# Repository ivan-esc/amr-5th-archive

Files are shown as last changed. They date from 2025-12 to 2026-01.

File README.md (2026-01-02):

AMR + AGV DIFFERENTIAL ROBOT - OMRON PROJECT (Mechatronics Eng. 5th semester AD25)
===================================
The objective of this project was to design a differential-wheeled robot capable of:
- Being operated manually with a mobile app joystick.
- Operating under a configurable AGV mode with station color detection.
- AMR mode with complete custom route configuration.
Following safety protocols regarding velocity and acceleration curves, energy consumption, emergency stops and awareness of nearby objects.
-----------------------------------
The repository includes the following:
- STM32f0Discovery project files (C)
- ESP32 project files (C++)
- Webpage history logs and final used file. (Javascript, HTML, CSS)
- MIT App Inventor project file for mobile app. (Block-based)
-----------------------------------
Main aspects of the project include:
- Direct register-level configuration of GPIOs using STM32 clock trees and peripheral memory maps.
- Timer prescaling and compare/capture configuration for PWM generation, ultrasonic time-of-flight measurement, and interrupt-driven non-blocking task scheduling.
- Implementation of UART communication with custom frame synchronization and desynchronization recovery between a Bluetooth client, STM32, and ESP32.
- Integration of multiple peripheral sensors using the I²C communication protocol on an STM32F0-based platform.
- Implementation of encoder-based odometry with inertial correction using first-order digital low-pass filtering.
- Closed-loop PID motor control using PWM, with acceleration-limited velocity references to mitigate current spikes and mechanical stress.
- AGV operation mode featuring robust line-following algorithms and floor-based station identification logic.
- Autonomous mobile robot (AMR) control supporting dynamically uploaded navigation routes.
- Implementation of visual feedback cues using addressable LED control libraries on the ESP32.
- ADC acquisition and conversion for temperature monitoring and battery-level measurement using voltage dividers.
- Additional audio and visual feedback features using buzzer-driven melodies and programmable LED patterns.
- Real-time WebSocket communication between the ESP32 and a web-based AMR control interface.
- Custom parametric trajectory generation using sinusoidal functions for x–y coordinate computation.
- Route smoothing for user-drawn paths using combined Chaikin subdivision and Gaussian filtering techniques.
- CSS-based layout and styling for an intuitive and user-friendly web interface.

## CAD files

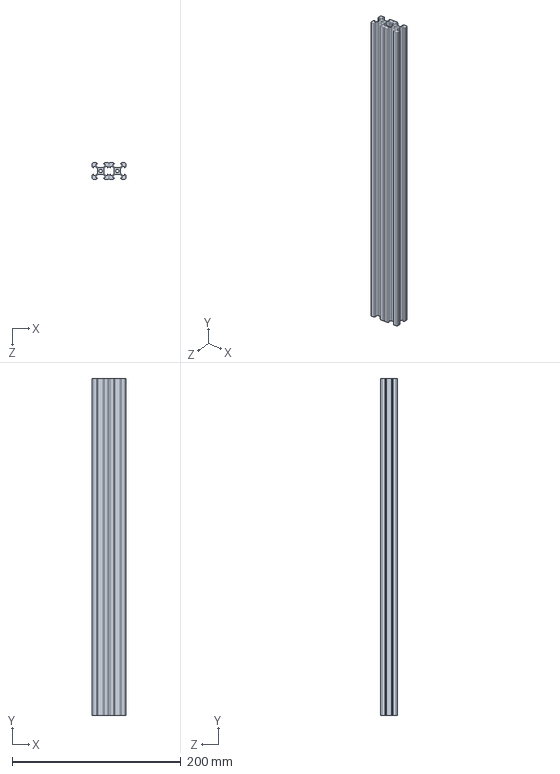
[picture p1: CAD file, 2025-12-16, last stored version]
Solidworksassembly/perfil_2040.SLDASM
40.0 x 400.0 x 20.0 mm
perfil_2020_lateral x 2

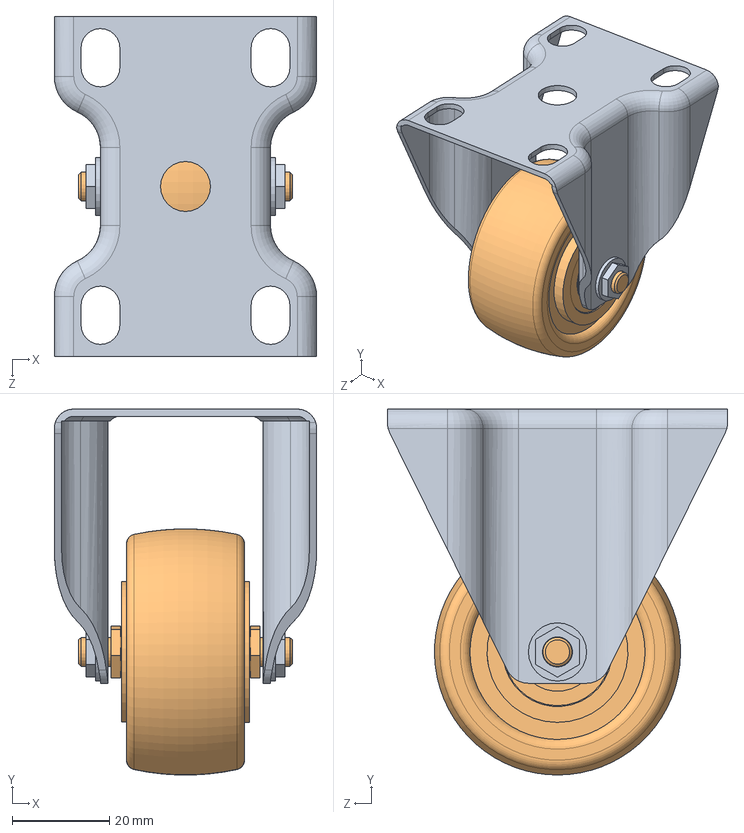
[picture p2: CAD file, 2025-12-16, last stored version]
Solidworksassembly/Standart_parts/2-inch-wheel-swivel-1.snapshot.1/CASTER WHEEL (2 inch) ASSY/2 inch WHEEL (FIXED) ASSY.SLDASM
54.0 x 75.3 x 70.0 mm
2 inch WHEEL BASE (FIXED)
2 inch WHEEL

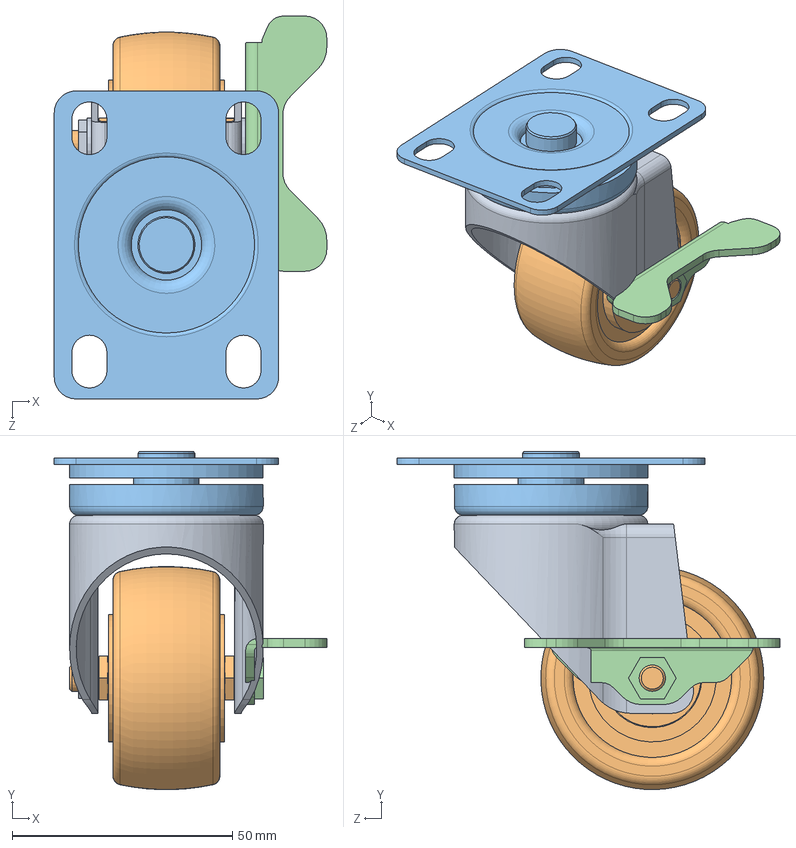
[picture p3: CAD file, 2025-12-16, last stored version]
Solidworksassembly/Standart_parts/2-inch-wheel-swivel-1.snapshot.1/CASTER WHEEL (2 inch) ASSY/2 inch WHEEL (SWIVEL) with BRAKES ASSY 2.SLDASM
61.9 x 76.8 x 87.0 mm
2 inch WHEEL BASE 2 (SWIVEL) with BRAKES
2 inch WHEEL
2 inch WHEEL UPPER BASE (SWIVEL) with BRAKES
CASTER WHEEL BASE LOCK (2IN)

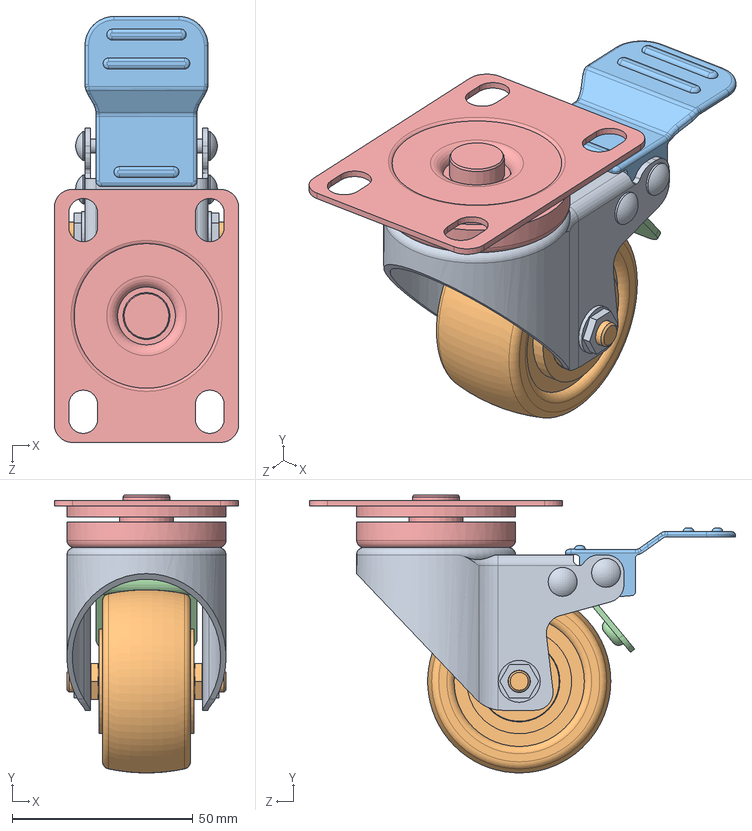
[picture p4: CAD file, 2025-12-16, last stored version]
Solidworksassembly/Standart_parts/2-inch-wheel-swivel-1.snapshot.1/CASTER WHEEL (2 inch) ASSY/2 inch WHEEL (SWIVEL) with BRAKES ASSY.SLDASM
51.0 x 76.8 x 117.8 mm
2 inch WHEEL BASE (SWIVEL) with BRAKES
2 inch WHEEL
2 inch WHEEL UPPER BASE - STOPPER 1 (SWIVEL) with BRAKES
2 inch WHEEL UPPER BASE - STOPPER 2 (SWIVEL) with BRAKES
2 inch WHEEL UPPER BASE (SWIVEL) with BRAKES

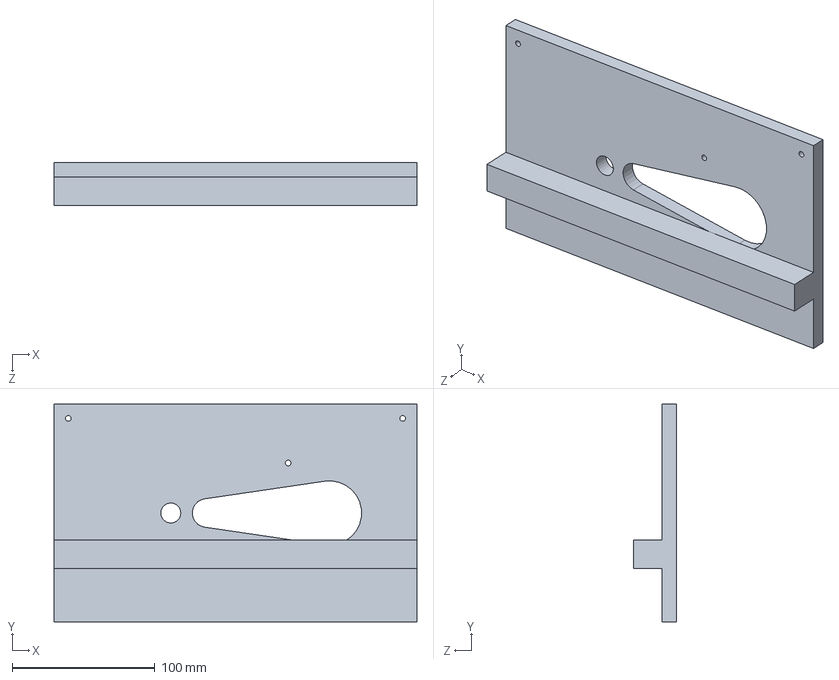
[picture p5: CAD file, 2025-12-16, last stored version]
Solidworksassembly/Actuadores/Motor_WSJ/base_dummy.SLDPRT
254.0 x 152.4 x 30.0 mm

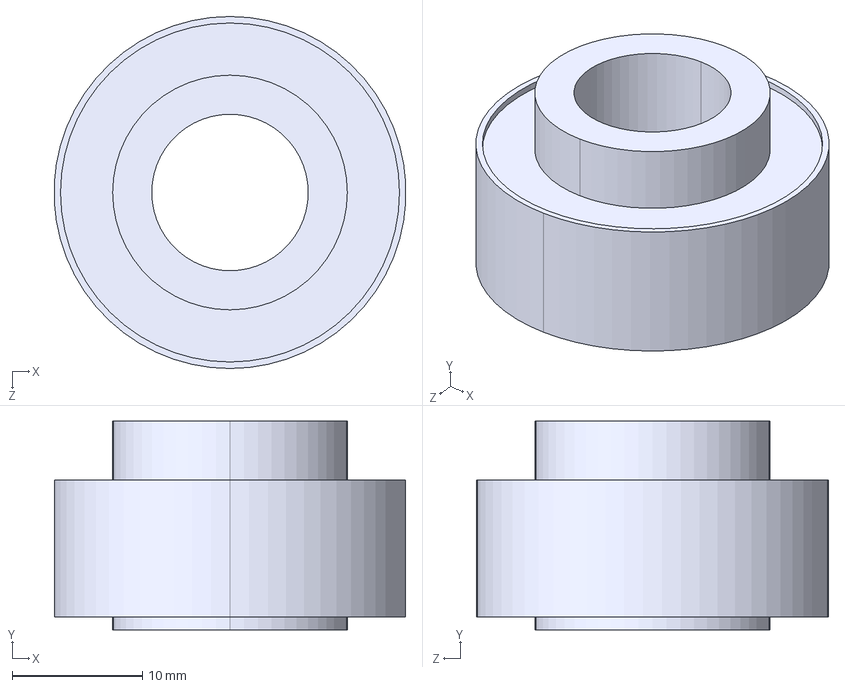
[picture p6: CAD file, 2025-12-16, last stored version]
Solidworksassembly/Actuadores/Motor_WSJ/flanged-support-bearing-kfl001-1.snapshot.2/подшипник KFL001.STEP
27.0 x 16.0 x 27.0 mm

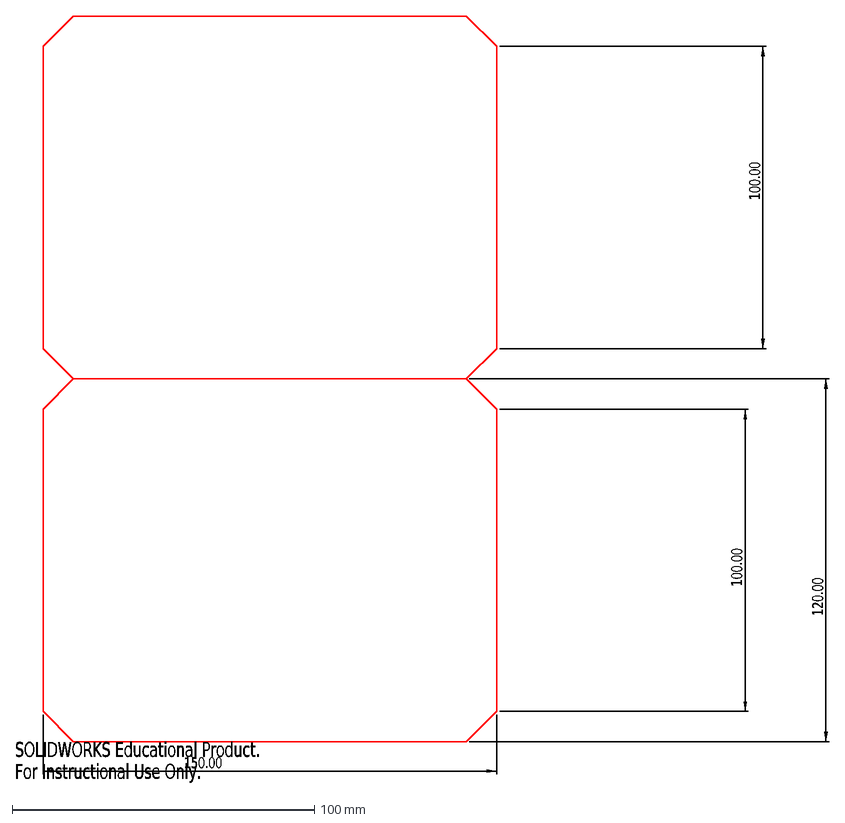
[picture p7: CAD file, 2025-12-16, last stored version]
Solidworksassembly/Addons/rectrojos.DXF
150.00
120.00
100.00
SOLIDWORKS Educational Product.
For Instructional Use Only.

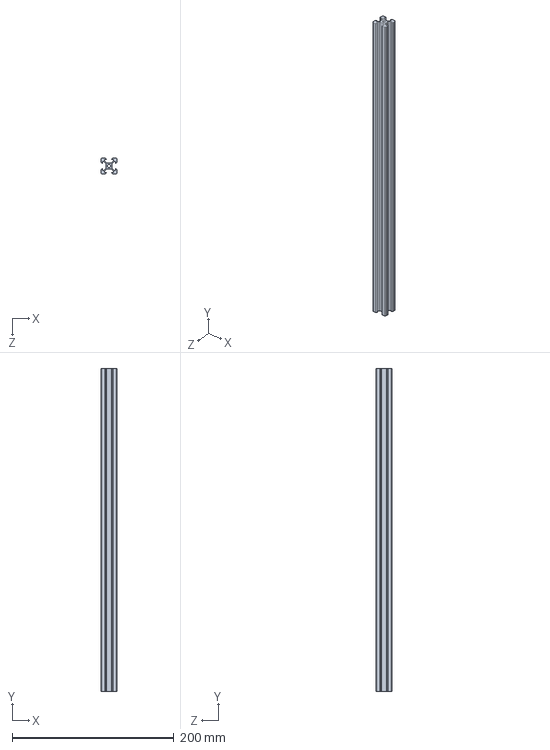
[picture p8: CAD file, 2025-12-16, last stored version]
Solidworksassembly/Diseño/perfil_2020_lateral.SLDPRT
20.0 x 400.0 x 20.0 mm

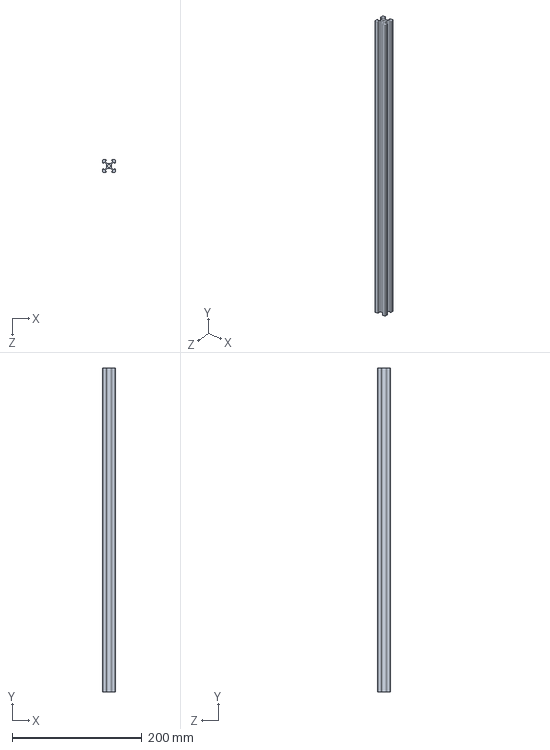
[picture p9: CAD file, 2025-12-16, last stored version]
Solidworksassembly/perfil_2020.SLDPRT
20.0 x 500.0 x 20.0 mm

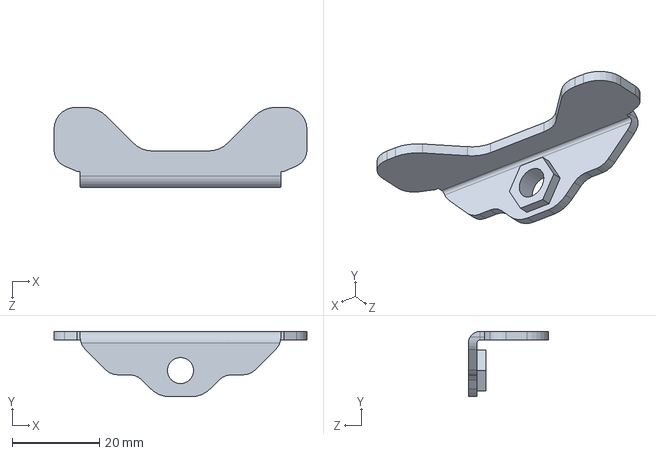
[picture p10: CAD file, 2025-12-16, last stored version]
Solidworksassembly/Standart_parts/2-inch-wheel-swivel-1.snapshot.1/CASTER WHEEL (2 inch) ASSY/CASTER WHEEL BASE LOCK (2IN).SLDPRT
58.0 x 15.0 x 18.4 mm

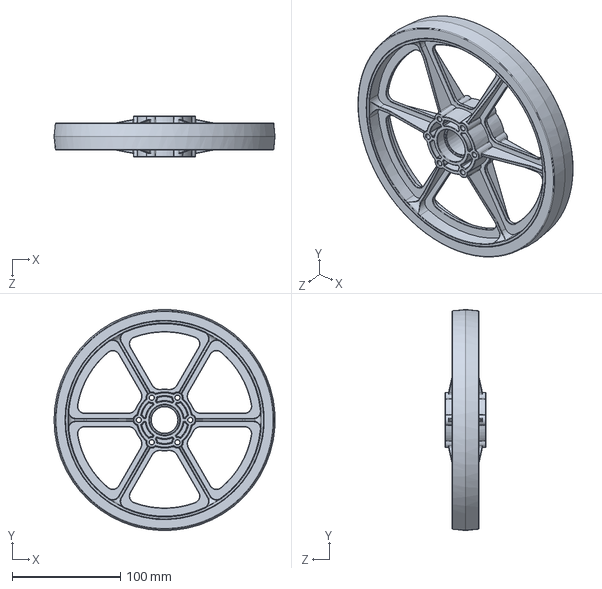
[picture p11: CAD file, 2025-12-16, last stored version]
Solidworksassembly/Standart_parts/am-0420 8in Wheel.SLDPRT
204.2 x 204.3 x 38.1 mm

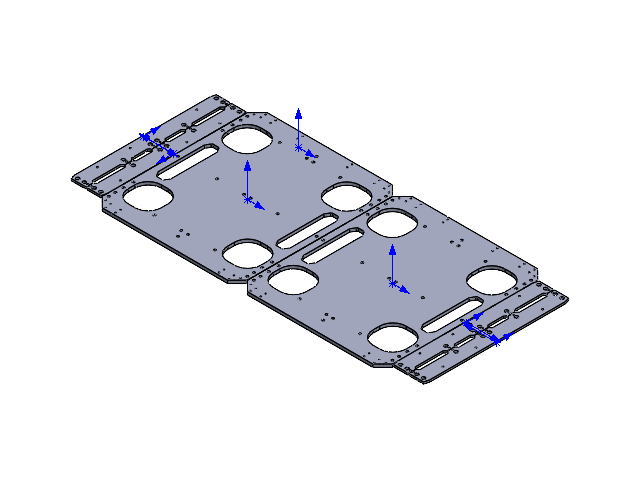
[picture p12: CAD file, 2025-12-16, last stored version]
Solidworksassembly/Manufactura/corte_laser_bases_x7.SLDASM
base_robot x 2
union_top x 4

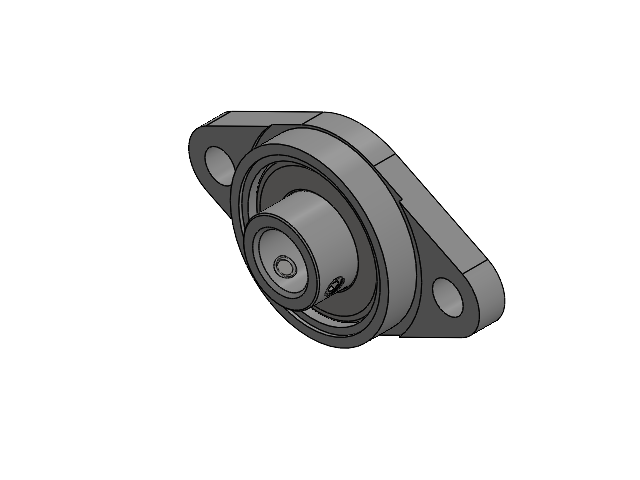
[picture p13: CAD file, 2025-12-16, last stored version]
Solidworksassembly/Standart_parts/KFL08/Zinc Alloy Pillow Block Flange Bearing KFL08 ID-8mm.SLDASM
Flange
Bearing 61801-2Z GB_T 276-94
DIN 988 - 13 x 19 x 1 x 2
Collar 8x12.35x11.35
IS_ 6094 - M3 x 2(1) x 3

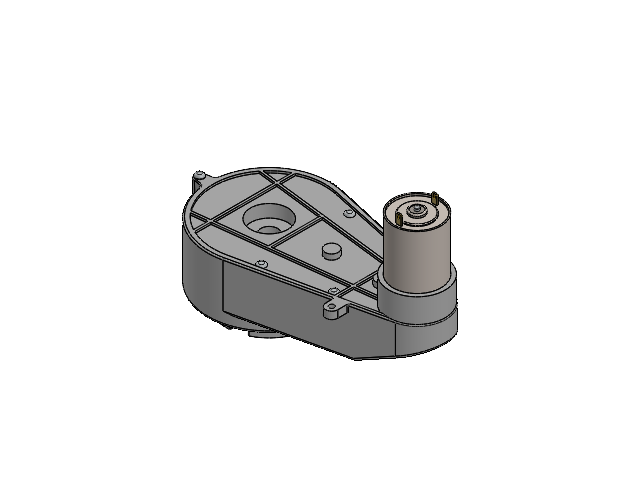
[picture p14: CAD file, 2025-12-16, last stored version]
Solidworksassembly/Actuadores/Motor_WSJ/motor_hub_WJS.SLDASM
motor_WJS
hub_motor_WJS

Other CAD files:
Solidworksassembly/Standart_parts/2-inch-wheel-swivel-1.snapshot.1/CASTER WHEEL (2 inch) ASSY/2 inch WHEEL (FIXED) ASSY 2.SLDASM
Solidworksassembly/Diseño/corte_laser_bases.SLDASM
Solidworksassembly/Standart_parts/2-inch-wheel-swivel-1.snapshot.1/CASTER WHEEL (2 inch) ASSY/2 inch WHEEL (SWIVEL) without BRAKES ASSY.SLDASM
Solidworksassembly/Standart_parts/KFL08/Collar 8x12.35x11.35.SLDPRT
Solidworksassembly/Actuadores/Motor_WSJ/base_motor.SLDPRT
Solidworksassembly/Actuadores/Motor_WSJ/base_wjs.DXF
Solidworksassembly/Actuadores/Motor_WSJ/base_wjs.SLDPRT
Solidworksassembly/Actuadores/Motor_WSJ/flanged-support-bearing-kfl001-1.snapshot.2/основние подшипника KFL001.SLDPRT
Solidworksassembly/Actuadores/Motor_WSJ/flanged-support-bearing-kfl001-1.snapshot.2/основние подшипника KFL001.STEP
Solidworksassembly/Actuadores/Motor_WSJ/flanged-support-bearing-kfl001-1.snapshot.2/подшипник KFL001.SLDPRT
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

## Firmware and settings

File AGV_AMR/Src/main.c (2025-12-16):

/*CODIGO EQUIPO NEGRO */

#include <stdint.h>
#include "stm32f051x8.h"
#include <stdlib.h>
#include <math.h>
#include <stdbool.h>

// Headers
#include "motor_pwm.h"
#include "encoders.h"
#include "ultrasonic.h"
#include "bluetooth.h"
#include "esp32_com.h"
#include "pid_diff_drive.h"
#include "i2c_color_imu.h"
#include "line_follow.h"
#include "odometry.h"
#include "amr_mode.h"

volatile uint32_t t = 0; //tiempo base
volatile uint8_t emergency_on = 0; //toggle emergencia


float w_ll = 0.0f;
float w_rr = 0.0f;
float VV = 0.0f;
float WW = 0.0f;

volatile int16_t x = 0; // Reworked mapped coordinate
volatile int16_t y = 0; // Reworked mapped coordinate


/////////////////////////////////////////////////////////////////////////////////////////////
///////////////////////////////    DECLARACION DE FUNCIONES    //////////////////////////////
/////////////////////////////////////////////////////////////////////////////////////////////

void BT_process_data(void);

void TIM14_Init(void); 			//10ms clock init
void ManualDrive(void);	//Manual mode (1) desired RPMs

static uint8_t amr_initialized = 0;   // 0 = not initialized, 1 = init done
void reset_references(void);

void emergency_stop(void);				//Actions when stopped
void check_emergency_buttons(void);		//EXTI for Emergency Pins (pending assignment)
void init_emergency_buttons(void);		//EXTI channel init for emergency
void PC7_Button_Check(void);
void PC7_Button_Init(void);

void SelectManualLEDCommand(void);		//Manual mode joystick LED aplication


int main(void)
{

	RCC->AHBENR |= RCC_AHBENR_GPIOBEN;
	RCC->APB2ENR |= RCC_APB2ENR_SYSCFGCOMPEN;
	RCC->APB1ENR |= RCC_APB1ENR_TIM3EN;
	NVIC->ISER[0] |= (1 << EXTI4_15_IRQn);

	i2c1_init(); //COLOR AND IMU

	USART2_Init(); //BLUETOOTH INIT CHECK
	USART1_Init(); //ESP32 COM INIT CHECK

	TIM14_Init(); //ROUTINE TIMER
	pwm_init(); //MOTOR CHANNELS CHECK
	IR_Sensors_Init(); //LINE FOLLOWER
	init_GPIO_EXTI_encoders(); //ENCODERS CHECK

	TIM3_init(); //ULTRASONIC TIMING CHECK
	init_GPIO_EXTI_ultrasonic(); //ULTRASONIC INIT CHECK

	__enable_irq(); //ENABLE INTERRUPTIONS CHECK
	mpu6050_init();
	//TCS34725_Init();

	Odometry_Init();
	init_emergency_buttons();
	PC7_Button_Init();

	AMR_Init();          // reset odometry, set internals, etc.

    /* Loop forever */

  	while (1){
        check_emergency_buttons();
  		if (imu_read_flag) {
			imu_read_flag = 0;
			imu_routine();
  		}
		if (color_read_flag) {
			color_read_flag = 0;
			color_detect_routine();
		}
	}
}




void TIM14_Init(void) { //10ms Timer Setup
	RCC->APB1ENR |= RCC_APB1ENR_TIM14EN;
    TIM14->PSC = 8 - 1;      // 8MHz/8 = 1MHz
    TIM14->ARR = 10000 - 1;  // 10ms period
    TIM14->DIER |= TIM_DIER_UIE;
    TIM14->CR1 |= TIM_CR1_CEN;
	NVIC_SetPriority(TIM14_IRQn, 1);  // Lower value = higher priority
    NVIC_EnableIRQ(TIM14_IRQn);
}
void TIM14_IRQHandler(void) { //10 ms timer
    if(TIM14->SR & TIM_SR_UIF) {
        TIM14->SR &= ~TIM_SR_UIF;  // Clear interrupt flag
        t += 10;

        //CONTINUOS SENSOR READS
        imu_read_flag = 1;
        check_emergency_buttons();
        velocidad_encoder();
		hcsr04_read();
		Odometry_Update();

        if (rx_buffer[0]!=255){PC7_Button_Check();}

        switch(menu_button){
        case 0: // OFF - Just Connected
        	reset_references();
        	break;
        case 1: //MANUAL MODE: idle
        	reset_references();
        	LED_action = 14;
        	break;
        case 2: //MANUAL MODE: running
        	ManualDrive();
        	break;
        case 3: //LINE FOLLOW: idle configuration
        	reset_references();
        	LED_action = 7;
        	break;
        case 4: // LINE FOLLOW MODE
        {
            if((distance_cm[2]>30.0f) && (distance_cm[0]>15.0f) && (distance_cm[3]>15.0f)){
				if(linea){
					seguir();}
            break;
            }
            else{
                VW_DifferentialDrive(0.0f,0.0f);
            	near_obj=1 ;
				V_current = 0;
				LED_action = 11;
				W_current = 0;
			break;
            }
        }
		case 5: //AMR: idle configuration
			reset_references();
			if(valid_indexes > 0){
				LED_action = 21;
			}
			else{
				LED_action = 19;
			}
			break;
        case 6: //AMR: RUNNING
            if((distance_cm[2]>30.0f) && (distance_cm[0]>15.0f) && (distance_cm[3]>15.0f)){
				LED_action = 0;
				if (!amr_initialized) {
					AMR_Start();
					amr_initialized = 1;
				}
				AMR_Update();

			break;
			}
			else{
				VW_DifferentialDrive(0.0f,0.0f);
				near_obj=1 ;
				V_current = 0;
				LED_action = 11;
				W_current = 0;
			break;
			}
        case 7: //SETTINGS
        	LED_action = 12;
        	reset_references();
        	break;
        case 8: // ESTOP?
        	reset_references();
        	LED_action = 13;
        	break;

        case 20: /// RGB TEST
			reset_references();
        	LED_action = 15;
			break;

		case 21: /// song1
			reset_references();
			LED_action = 31;
			break;

		case 22: /// song1
			reset_references();
			LED_action = 30;
			break;
		}


		static uint8_t last_led_action = 0xFF;
		uint8_t cur = LED_action; // Mandar comand a ESP32 solo cuando cambia
		if (cur != last_led_action) {
			USART1_send(cur);
			last_led_action = cur;
		}

		if (t >= 70) { //MANDAR DATOS DE BLUETOOTH CADA 200ms
			BT_process_data();
			BT_SendTelemetry();
			t = 0;
		}
    }
}



void ManualDrive(void){
	//Logic calculation based on 250x250 map, where 125x125 is defined as center
	//Assume a +-30 deadzone for generous inputs

	 x = raw_x - 125; //Set initial coords to (0,0)
     y = 125- raw_y;
     if (abs(x) < 30){ x = 0;}
     if (abs(y) < 30){ y = 0;}
     //Normalize
     V_req = y*0.8f/125.0f; //Max speed will be set to 0.8m/s for plot convenience
     W_req = x*0.8f*2.5f/125.0f; // Angular speed

     VW_DifferentialDrive(V_req,W_req);
     SelectManualLEDCommand();
}


void BT_process_data(void) {
    // Convert from RPM to rad/s
    w_ll = rpm_1_filtered * 2.0f * 3.14159265359f / 60.0f;
    w_rr = rpm_2_filtered * 2.0f * 3.14159265359f / 60.0f;

    // Compute linear and angular velocity
    VV = (WHEEL_RADIUS * (w_rr + w_ll)) / 2.0f;
    WW = (WHEEL_RADIUS * (w_rr - w_ll)) / WHEEL_DISTANCE;

    linear_velocity = (uint8_t)((fabsf(VV)*10) + 0.5f);
    angular_velocity = (uint8_t)((fabsf(WW)*10) + 0.5f);

    tmp_data = temperature10;
    //voltage_sent = voltage10;
    voltage_sent = 118;

    posx_small = (uint8_t)(pos_x_mm & 0xFF);        // byte bajo  (LSB)
    posx_big   = (uint8_t)((pos_x_mm >> 8) & 0xFF); // byte alto  (MSB)

    posy_small = (uint8_t)(pos_y_mm & 0xFF);
    posy_big   = (uint8_t)((pos_y_mm >> 8) & 0xFF);

}

void init_emergency_buttons(void) {
    // Enable GPIOC clock
    RCC->AHBENR |= RCC_AHBENR_GPIOCEN;

    // Set PC6 as inputs (MODER = 00)
    GPIOC->MODER &= ~(3 << (6 * 2));

    // Optional: enable pull-downs if buttons are active-high
    GPIOC->PUPDR &= ~(3 << (6 * 2)); // Clear
}
void check_emergency_buttons(void) {
    // If PC6 is HIGH
    if ((GPIOC->IDR & (1 << 6))) {
        emergency_stop();
    }
    else{
    	emergency_on = 0;
    }
}
void emergency_stop(void) {
    menu_button = 0;
    emergency_on = 1;
    reset_references();
	LED_action = 13;
}

// ----- Initialize PC7 as input -----
void PC7_Button_Init(void) {
    // Enable GPIOC clock
    RCC->AHBENR |= RCC_AHBENR_GPIOCEN;

    // Set PC7 as input (MODER = 00)
    GPIOC->MODER &= ~(3 << (7*2));

    // Optional: enable pull-down or pull-up if needed
    GPIOC->PUPDR &= ~(3 << (7*2));   // clear
    GPIOC->PUPDR |=  (1 << (7*2));   // pull-up
}
// ----- Check PC7 periodically -----
void PC7_Button_Check(void) {
    if (GPIOC->IDR & (1 << 7)) {  // if PC7 is HIGH
        menu_button = 6;
    }
    else {
        menu_button = 0;          // optional: reset if low
    }
}

void SelectManualLEDCommand(void) {
    // Default = idle
    int cmd = 0;
    if (y > 30 && abs(x) < 40) {
        // Forward
        cmd = 3;
    }
    else if (y < -30 && abs(x) < 40) {
        // Backward
        cmd = 4;
    }
    else if (x < -30 /*&& abs(y) < 40*/) {
        // Left
        cmd = 5;
    }
    else if (x > 30 /*&& abs(y) < 40*/) {
        // Right
        cmd = 6;
    }
    else if (abs(x) < 30 && abs(y) < 30) {
        // Deadzone → Idle
        cmd = 0;
    }
    LED_action = cmd;
}
void reset_references(void){
	PID_PWM(0,0);
	left_RPWM(0);
	left_LPWM(0);
	right_RPWM(0);
	right_LPWM(0);
	rpm_ref_left=0;
	rpm_ref_right=0;
	V_current = 0.0f;
	W_current = 0.0f;
	last_position_error = 0.0f;
	exit_timer = 0;
	station_done = true;     // back to normal mode
	leaving_station = false;  // fully reset
	counter_stations = 1;
	AMR_Stop();             // <- resets AMR state machine, indices, odometry via Reset_x_y()
	amr_initialized = 0;    // allow re-init next time AMR is selected


}

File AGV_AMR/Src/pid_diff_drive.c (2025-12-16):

///////////////////////////////////////////////
////// PID AND DIFFERENTIAL DRIVE SOURCE //////
///////////////////////////////////////////////
/*
 INPUT: V_req and W_req rpm_ref_l_r
 OUTPUT: PID FOR PWM
 */

#include "pid_diff_drive.h"

// Left wheel PID
float error_l     = 0.0f;
float error_l_dt   = 0.0f;
float int_error_l = 0.0f;
float der_error_l = 0.0f;

// Right wheel PID
float error_r     = 0.0f;
float error_r_dt   = 0.0f;
float int_error_r = 0.0f;
float der_error_r = 0.0f;

float kp_l = 10.0f;
float ki_l = 3.0f;
float kd_l = 0.0f;

float kp_r = 10.0f;
float ki_r = 3.0f;
float kd_r = 0.0f;

int16_t pwm_left_cmd = 0,pwm_right_cmd = 0;
float pwm_l = 0,pwm_r = 0;

//avoids killing the hbridge
float last_pwm_l = 0.0f, last_pwm_r = 0.0f;
uint8_t changed_direction_l = 0, changed_direction_r = 0;

float V_req = 0; //Linear speed MAX: 2m/s
float W_req = 0; //Angular speed MAX: 2rad/s i think
float w_l = 0, w_r = 0; // En rad/s
float rpm_ref_left = 0, rpm_ref_right = 0; //convert w_l and w_r to rpms

void PID_PWM(float ref_l,float ref_r){ //1 = left, 2 = right
    // ----- LEFT MOTOR PID -----
	error_l = ref_l - rpm_1_filtered;
	if (fabsf(pwm_l) < 650.0f && fabsf(ref_l) > 1.0f) {
		int_error_l += 0.01f * error_l;
	}
	else if (fabsf(ref_l) <= 1.0f) {
		int_error_l = 0.0f;
	}
	der_error_l = (error_l - error_l_dt) / 0.01f;
	error_l_dt = error_l;

	// ----- RIGHT MOTOR PID -----
	error_r = ref_r - rpm_2_filtered;

	if (fabsf(pwm_r) < 650.0f && fabsf(ref_r) > 1.0f) {
	    int_error_r += 0.01f * error_r;
	}
	else if (fabsf(ref_r) <= 1.0f) {
	    int_error_r = 0.0f;
	}

	der_error_r = (error_r - error_r_dt) / 0.01f;
	error_r_dt = error_r;


	pwm_l = kp_l * error_l + ki_l * int_error_l + kd_l * der_error_l;
	pwm_r = kp_r * error_r + ki_r * int_error_r + kd_r * der_error_r;

	// ----- ANTI WIND UP (MAX PWM EXPERIMENTAL AROUND 2M/S = 77% DUTY -----
	if (pwm_l > 650.0f) {
		pwm_l = 650.0f;
	} else if (pwm_l < -650.0f) {
		pwm_l = -650.0f;
	}
	if (pwm_r > 650.0f) {
		pwm_r = 650.0f;
	} else if (pwm_r < -650.0f) {
		pwm_r = -650.0f;
	}

	// Map to actual macros (BTS driver expects positive duty and direction pins)
	// ====================================================
	// SAFETY LOGIC — DIRECTION CHANGE DETECTION
	// ====================================================
	// Detect sign change (zero crossing)
	if ((last_pwm_l * pwm_l < 0.0f) || (fabsf(pwm_l) < 5.0f)) {
		left_LPWM(0);
		left_RPWM(0);
		changed_direction_l = 1;
	} else {
		changed_direction_l = 0;
	}

	if ((last_pwm_r * pwm_r < 0.0f) || (fabsf(pwm_r) < 5.0f)) {
		right_LPWM(0);
		right_RPWM(0);
		changed_direction_r = 1;
	} else {
		changed_direction_r = 0;
	}

	// ====================================================
	// APPLY PWM ONLY IF NO CHANGE
	// ====================================================
	if (!changed_direction_l) {
		if (pwm_l >= 0.0f) {
			left_RPWM((uint16_t)pwm_l);
			left_LPWM(0);
		} else {
			left_LPWM((uint16_t)(-pwm_l));
			left_RPWM(0);
		}
	}

	if (!changed_direction_r) {
		if (pwm_r >= 0.0f) {
			right_RPWM((uint16_t)pwm_r);
			right_LPWM(0);
		} else {
			right_LPWM((uint16_t)(-pwm_r));
			right_RPWM(0);
		}
	}
	//Safety delta
	last_pwm_l = pwm_l;
	last_pwm_r = pwm_r;
	 // Debug save
	pwm_left_cmd = (int)pwm_l;
	pwm_right_cmd = (int)pwm_r;
}

void VW_DifferentialDrive(float V_req,float W_req){
    w_l = (V_req / WHEEL_RADIUS) + (WHEEL_DISTANCE * W_req / (2.0f * WHEEL_RADIUS));
    w_r = (V_req / WHEEL_RADIUS) - (WHEEL_DISTANCE * W_req / (2.0f * WHEEL_RADIUS));

    rpm_ref_left  = w_l * 60.0f / (2.0f * 3.14159265358979323846f);
    rpm_ref_right = w_r * 60.0f / (2.0f * 3.14159265358979323846f);

    PID_PWM(rpm_ref_left,rpm_ref_right);

}

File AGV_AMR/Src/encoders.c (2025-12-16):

//////////////////////////////
////// ENCODERS  SOURCE //////
//////////////////////////////
/*
 INPUT: EXTI-PULSES AND INIT
 OUTPUT: RPM-FILTERED
 */

#include "encoders.h"

/////////////////////////////////////////////////////////////////////////////////////////////
///////////////////////////////      ENCODERS            ////////////////////////////////////
/////////////////////////////////////////////////////////////////////////////////////////////

volatile int32_t encoderPos1 = 0, encoderPos2 = 0; //Absolute Position based on start up
volatile uint8_t direction1 = 0, direction2 = 0; // 1 cockwise, 2 counter cockwise
volatile float delta_Pos1 = 0.0f, delta_Pos2 = 0.0f; //Diferencial cada 10ms
volatile float lastPos1 = 0.0f, lastPos2 = 0.0f; //Referencia encoder pos para delta

#define Aa 0.0951625819640404f   // coefficient for input (transfer funct)
#define Bb -0.904837418035960f   // coefficient for previous output (transfer funct)
float rpm_1_filtered = 0.0f;    // GOOD PWM 1 = left
float rpm_2_filtered = 0.0f;	// GOOD PWM 2 = right
float prev_rpm_1 = 0.0f; //Referencia rpm para transfer function
float prev_rpm_2 = 0.0f; //Referencia rpm para transfer function

// --- call this once at startup (after clocks/GPIO init) ---
void init_GPIO_EXTI_encoders(void) {
    // Ensure GPIOA / GPIOB clocks enabled
    RCC->AHBENR |= RCC_AHBENR_GPIOAEN | RCC_AHBENR_GPIOBEN;

    // Enable SYSCFG clock (needed to route EXTI lines)
    RCC->APB2ENR |= RCC_APB2ENR_SYSCFGEN;

    // Configure inputs with pull-ups:
    // Encoder1: PB4 (A), PB5 (B)
    GPIOB->MODER &= ~((3 << (4 * 2)) | (3 << (5 * 2)));
    GPIOB->PUPDR &= ~((3 << (4 * 2)) | (3 << (5 * 2)));
    GPIOB->PUPDR |=  ((1 << (4 * 2)) | (1 << (5 * 2))); // pull-up

    // Encoder2: PA6 (A), PA7 (B)
    GPIOA->MODER &= ~((3 << (6 * 2)) | (3 << (7 * 2)));
    GPIOA->PUPDR &= ~((3 << (6 * 2)) | (3 << (7 * 2)));
    GPIOA->PUPDR |=  ((1 << (6 * 2)) | (1 << (7 * 2))); // pull-up

    // Map EXTI lines:
    // SYSCFG->EXTICR[1] contains EXTI4..7 mapping (4 fields x 4 bits)
    // clear EXTI4..7 nibble fields first
    SYSCFG->EXTICR[1] &= ~((0xF << (0*4)) | (0xF << (1*4)) | (0xF << (2*4)) | (0xF << (3*4)));

    // EXTI4 -> PB  (value 1 for port B in EXTICR field)
    SYSCFG->EXTICR[1] |= (1 << (0*4));   // EXTI4 = PB
    // EXTI6 -> PA  (value 0 for port A; clearing is enough; left explicit)
    // (we already cleared, so EXTI6 = PA)

    // Unmask EXTI lines for the encoder A pins and enable rising edge trigger
    EXTI->IMR |= (1 << 4) | (1 << 6);    // EXTI4 (encoder1 A), EXTI6 (encoder2 A)
    EXTI->RTSR |= (1 << 4) | (1 << 6);   // rising edge only (keep same behavior as before)
    // Optionally enable falling edges too:
    // EXTI->FTSR |= (1<<4) | (1<<6);

    // NVIC: EXTI4..15 IRQ covers EXTI4..15
    NVIC_EnableIRQ(EXTI4_15_IRQn);
}

void update_encoder(uint8_t encoder) {
    uint8_t B;
    if (encoder == 1) {
        B = (GPIOB->IDR >> 5) & 1;
    } else {
        B = (GPIOA->IDR >> 7) & 1;
    }

    if (B == 0) {
        if (encoder == 1) { encoderPos1--; direction1 = 2; }
        else { encoderPos2++; direction2 = 1; }
    } else {
        if (encoder == 1) { encoderPos1++; direction1 = 1; }
        else { encoderPos2--; direction2 = 2; }
    }
}

void velocidad_encoder(void){
    // --- Calculate raw RPM from encoder ---
    delta_Pos1 = encoderPos1 - lastPos1;
    float rpm_1_raw = (delta_Pos1 * 60.0f) / 5.0f;

    delta_Pos2 = encoderPos2 - lastPos2;
    float rpm_2_raw = (delta_Pos2 * 60.0f) / 5.0f;

    lastPos1 = encoderPos1;
    lastPos2 = encoderPos2;

    // --- Apply digital filter ---
    rpm_1_filtered = Aa * rpm_1_raw - Bb * prev_rpm_1;
    rpm_2_filtered = Aa * rpm_2_raw - Bb * prev_rpm_2;

    // --- Update states for next iteration ---
    prev_rpm_1 = rpm_1_filtered;
    prev_rpm_2 = rpm_2_filtered;
}

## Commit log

2025-12-16 Solidworks Assembly Files
    [2 inch WHEEL (FIXED) ASSY 2.SLDASM, 2 inch WHEEL (FIXED) ASSY.SLDASM, 2 inch WHEEL (SWIVEL) with BRAKES ASSY 2.SLDASM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]
2025-12-16 ESP32 Code added
    [2 inch WHEEL (FIXED) ASSY 2.SLDASM, 2 inch WHEEL (FIXED) ASSY.SLDASM, 2 inch WHEEL (SWIVEL) with BRAKES ASSY 2.SLDASM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]
2025-12-16 STM32 Full IDE Project
